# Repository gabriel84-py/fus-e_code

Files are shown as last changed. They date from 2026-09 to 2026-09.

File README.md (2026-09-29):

# LUNATIK

A flight computer we designed, built and flew in a our model rocket, to find out which way of detecting apogee really fires first: the barometer, the accelerometer, or both fused with a Kalman filter.

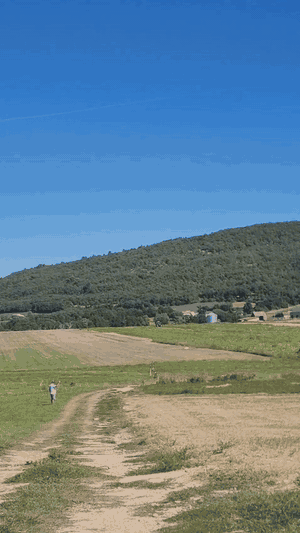
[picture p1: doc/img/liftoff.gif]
LUNATIK lifting off


**[Watch the full flight](video-first-flight-LUNATIK.mp4)** | **[Schematic (PDF)](Schematic_LUNATIK-v1.pdf)** | **[Try the ground station without a rocket](#try-it-without-a-rocket)**

Raspberry Pi Pico 2 (RP2350), CircuitPython, LoRa telemetry, SD logging. Made by Sidonie and me (Gabriel), two high school students from Villeneuve-lès-Avignon, France, for the French Physics Olympiad (Olympiades de Physique France).

## Why we built it

Most hobby flight computers detect apogee the same way: wait until the altitude drops a few samples in a row, then fire the parachute. I wanted to know if that actually works, and how late it is.

The whole project ended up fitting in one sentence: **the accelerometer is a good clock but a bad ruler, and the barometer is a good ruler but a bad clock.**

- Integrate an accelerometer twice and any tiny bias `b` becomes an altitude error of `1/2 b t^2`. Great for the first second, useless after ten.
- A barometer knows where you are, but to be sure you've passed the top you have to wait until you're `dh` below it. That costs `sqrt(2 dh / g)` seconds, however good the sensor is.

So LUNATIK fuses both with a 3-state Kalman filter (altitude, vertical velocity, accelerometer bias), and we measured whether that is actually better instead of assuming it.

## It flew

LUNATIK flew in September 2026. The GIF at the top is the liftoff, and the full clip is in the repo: [`video-first-flight-LUNATIK.mp4`](video-first-flight-LUNATIK.mp4).

## What's on the board

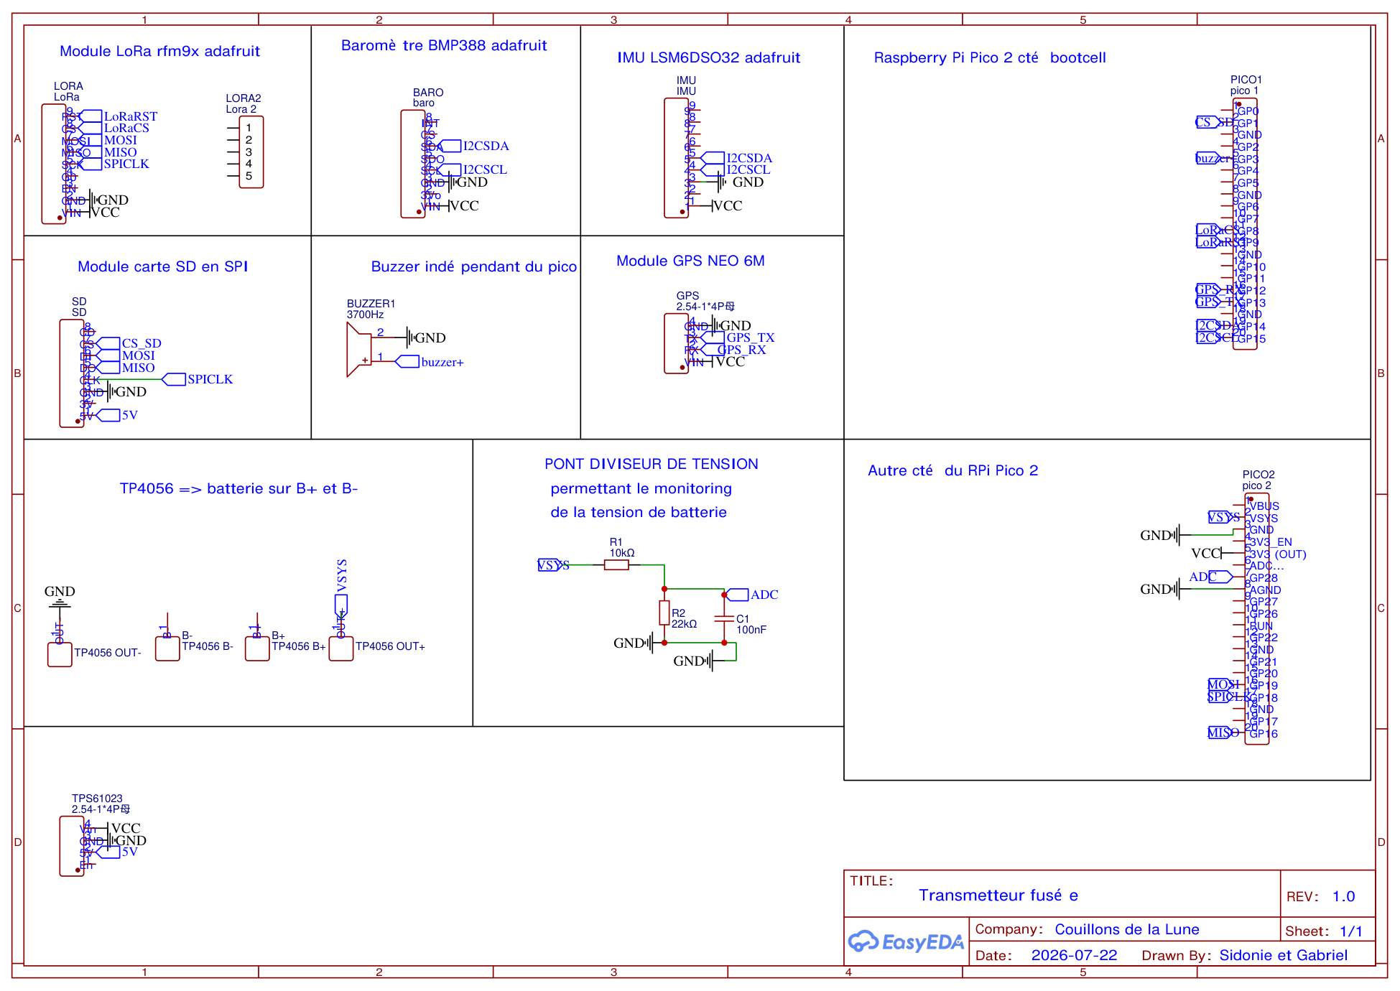
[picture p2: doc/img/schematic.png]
LUNATIK schematic


| Part | Job |
|---|---|
| Raspberry Pi Pico 2 (RP2350) | runs everything, in CircuitPython |
| BMP388 (I2C) | pressure, so altitude |
| LSM6DSO32 (I2C) | accelerometer +/-16 g and gyro, 208 Hz |
| RFM9x LoRa 868 MHz (SPI) | telemetry to the ground |
| SD card module (SPI) | full flight log in CSV |
| NEO-6M GPS (UART) | position, to find the rocket afterwards |
| TP4056 + LiPo | charging and power |
| TPS61023 boost | 5 V for the SD card |
| 3700 Hz buzzer | so you can hear what state it's in |
| 10k/22k divider + 100 nF | battery voltage on the ADC |

Schematic done in EasyEDA by both of us.

## How it works

**State machine.** `PRE_LAUNCH -> BOOST -> COAST -> APOGEE -> DESCENT -> LANDED`. Every transition needs several confirming samples and has a backup timer, because we only had one motor and the firmware had to work the first time.

**Kalman filter.** The 3x3 covariance is stored as 6 plain floats instead of a matrix, so no numpy and no allocation on the Pico. The full update costs 0.51 ms. The process noise isn't the datasheet value: it has to cover gravity leaking into the axis when the rocket tilts, which the model doesn't know about.

**Apogee.** We first tried "N decreases in a row" and threw it out after measuring it. Near apogee the rocket drops about 4 cm between two samples, while the noise on that difference is about 24 cm. The signal-to-noise ratio is 0.18, so the criterion is basically flipping a coin. LUNATIK instead fires when the *fused* altitude is 0.51 m (3 sigma of the baro noise) below the highest point seen, confirmed twice.

**Radio off during the climb.** One LoRa packet blocks the loop for about 200 ms. In simulation, leaving it on during the climb made the altitude error go from 0.21 to 0.54 m, so the radio stays quiet from liftoff to apogee.

## Numbers

Measured on the real board, except the two lines marked "sim" (OpenRocket trajectory with realistic noise added).

| | |
|---|---|
| Loop rate during the climb | 32.3 Hz |
| Barometer read (OSx8) | 21.4 ms, 69 % of the loop |
| Full Kalman update | 0.51 ms, 1.6 % of the loop |
| Baro noise, measured | 15.7 cm |
| Kalman altitude uncertainty | 8.7 cm (1.8x better than the raw baro) |
| Apogee detection delay (sim) | 0.37 +/- 0.02 s |
| Lead over the motor's ejection charge (sim) | 0.188 s |

The one that surprised me: the maths costs almost nothing. The barometer eats most of the loop, so optimising the filter would have been pointless. Reading pressure and temperature in one call instead of two took the loop from 19 Hz to 32 Hz.

## Things that went wrong

- **The SD card was wired to VBUS on the V3 board.** It worked perfectly on the bench, because the bench was on USB. On battery, in flight, it would have been dead. We only caught it by writing a script to check the Gerbers before ordering. The new board powers it through the TPS61023 boost.
- **The burnout threshold was never crossed.** We took it from OpenRocket's "vertical acceleration" column, but that column doesn't include gravity, and an accelerometer measures gravity plus acceleration. The rocket always switched to COAST on the 5 s backup timer, 2.3 s late. Now the threshold is compared to the real sensor value (column + 9.81).
- **Apogee fired on the launch pad.** Feeding the detector raw baro altitude, noise alone crossed the threshold before liftoff in 2 runs out of 5. Feeding it the Kalman altitude fixed it.
- **Still open:** under the parachute the rocket swings, gravity leaks into the accelerometer axis, and the filter becomes overconfident (1.5 m of real error for 8.5 cm announced). Fixing that means adding attitude from the gyro, so going from 3 states to at least 6.

## The flight
 
LUNATIK flew in September 2026 and logged the whole thing to SD at about 30 Hz. This is the raw log, straight from the card:
 
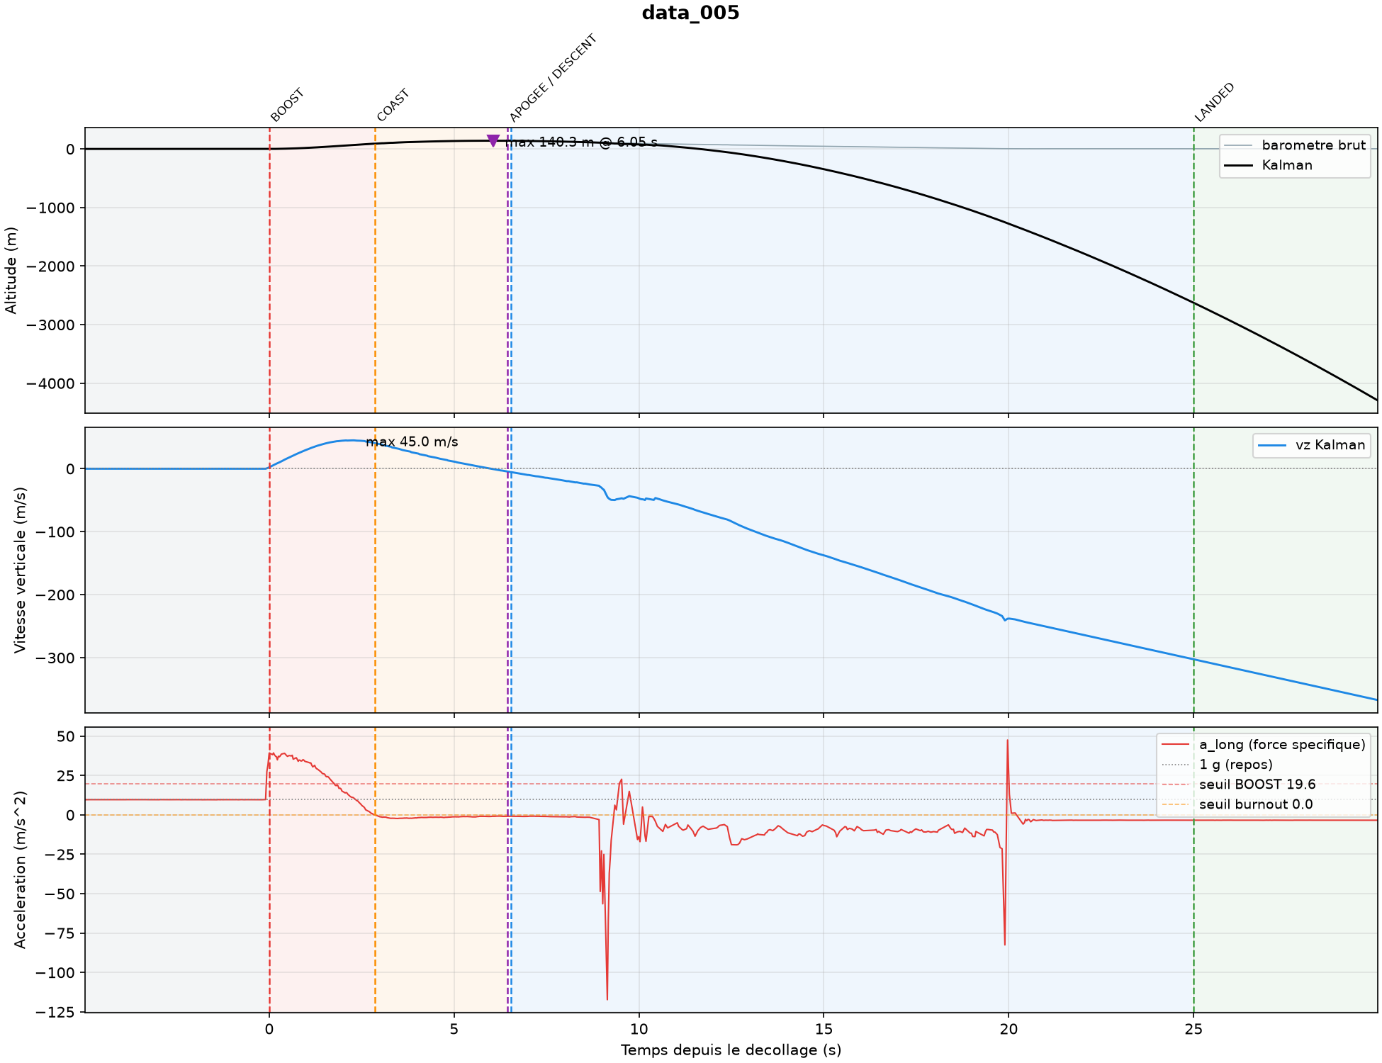
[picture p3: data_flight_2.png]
Flight data

 
| | |
|---|---|
| Apogee | 140 m, 6.1 s after liftoff |
| Peak acceleration | 4.0 g, top speed 45 m/s |
| Liftoff detected | 63 ms after the first sample above 2 g (needs 3 in a row) |
| Burnout detected | 2.9 s after liftoff, on the sensor threshold, not the backup timer |
| Apogee called by LUNATIK | **0.45 s after the top** (simulation said 0.37 s) |
| Motor ejection charge | 2.5 s after LUNATIK called apogee, 24 m lower |
| Descent under parachute | 9.3 m/s |
| Landing detected | 5 s after touchdown, as designed |
 
The result I care most about: the motor's delay charge opened the parachute 2.5 s after the top, with the rocket already 24 m down. LUNATIK knew it was at apogee half a second after the top. On this flight, electronic deployment would have opened the chute a lot earlier and higher.
 
**What went wrong in the air.** Look at the blue curve after the parachute opens. Under the chute the rocket hangs upside down, so the accelerometer reads about -10 m/s^2 instead of +10. The filter still subtracts its +9.81 bias, sees 20 m/s^2 of acceleration that doesn't exist, and drifts. Once it was more than 30 m off, the innovation gate (there to protect the filter from one bad baro reading) started rejecting *every* baro reading, so it never came back. It ended the flight thousands of meters underground.
 
Two lessons: a gate needs a way back (reset on the barometer after too many rejections), and the model needs attitude, or at least needs to stop trusting the accelerometer under the chute. The good news is that landing detection runs on the raw barometer, not on the filter, so the state machine still called LANDED correctly.
 
<p align="center">
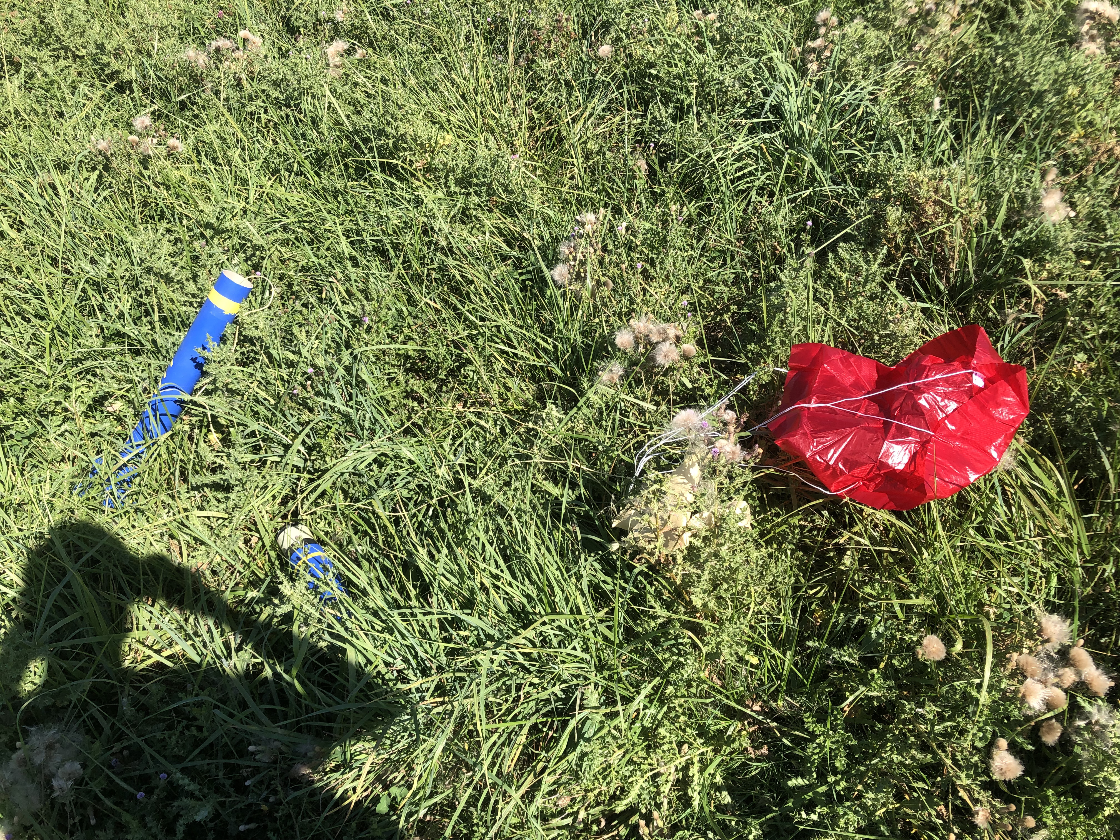
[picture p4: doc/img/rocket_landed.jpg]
The rocket after landing
  
</p>

## Try it without a rocket

The ground station has a simulation mode that generates fake telemetry, so you can see it running with no hardware:

```bash
git clone https://github.com/gabriel84-py/fus-e_code.git
cd fus-e_code/scripts
pip install pyserial matplotlib
python dashboard.py --simulate
```

Needs Python 3 with Tkinter (included with the python.org installer on Windows and macOS; `sudo apt install python3-tk` on Debian/Ubuntu).

To run the real thing: flash CircuitPython on a Pico 2, copy everything in `src/` to the `CIRCUITPY` drive, and format the SD card as FAT32 (full format, not quick). On the pad, the accelerometer bias shown on the debug line has to settle near **+9.81**. If it goes to -9.81 the axis is upside down and the rocket will never detect liftoff.

## About the logged hours

Hackatime only tracked the code. Everything on the hardware side (soldering, wiring, building and integrating the rocket, launch day) wasn't recorded, because I didn't know there was a tool to record build sessions until the rocket had already flown. So the hours on this project are lower than the time I actually spent on it.

## Credits

- Adafruit for the CircuitPython drivers, OpenRocket for the trajectory simulations.
- Olympiades de Physique France, and Hack Club for Stardance.

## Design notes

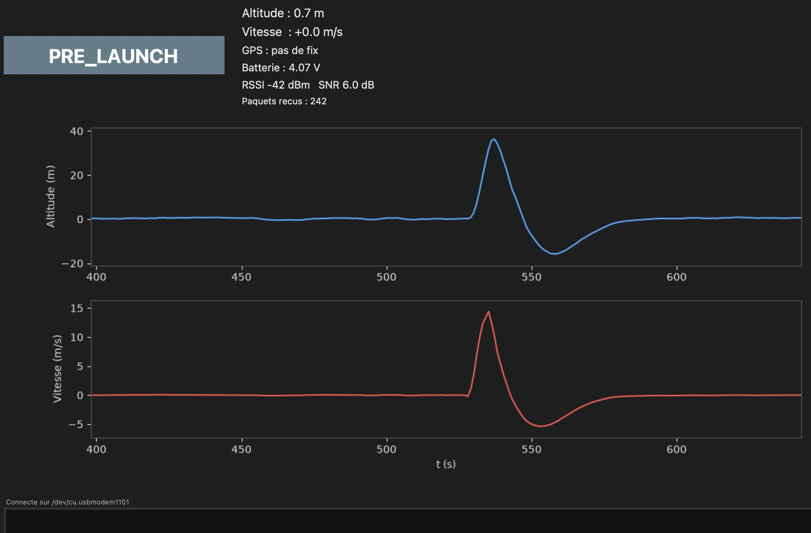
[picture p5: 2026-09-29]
doc/img/dashboard.png

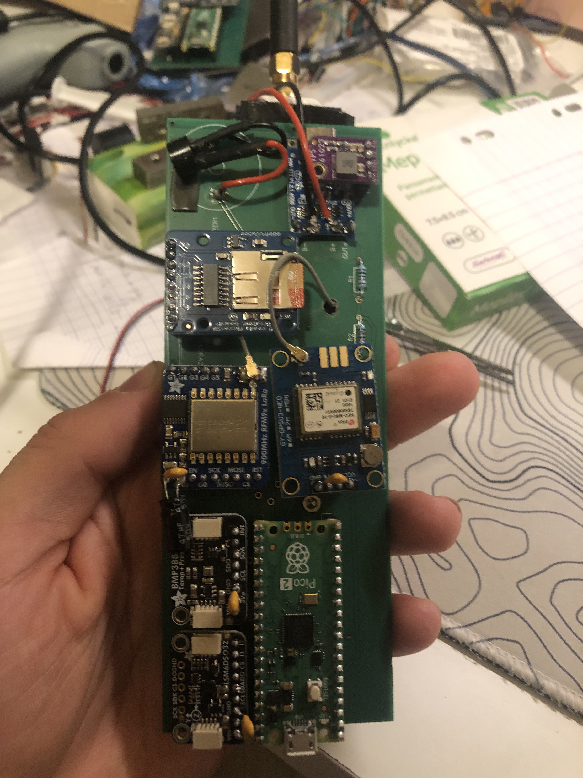
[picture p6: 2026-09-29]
doc/img/hero.jpg

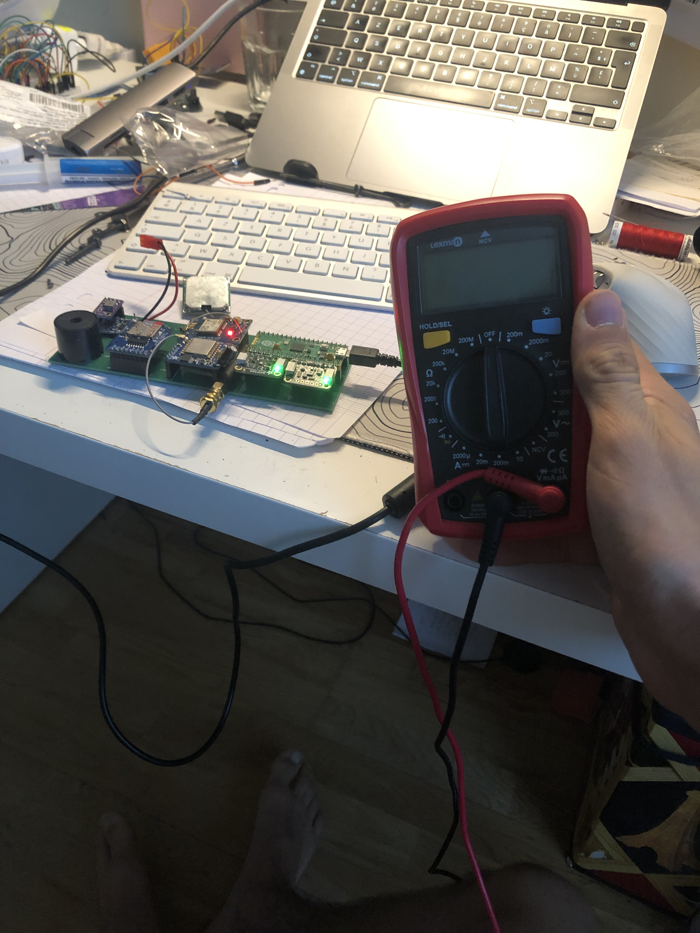
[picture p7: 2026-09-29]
doc/img/multimeter_pcb.jpg

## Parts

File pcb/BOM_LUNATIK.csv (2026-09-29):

ID | Name | Designator | Footprint | Quantity | Manufacturer Part | Manufacturer | Supplier | Supplier Part | Price
1 | 2.54-1*4P母 | TPS61023,GPS | HDR-TH_4P-P2.54-V-F | 2 | 2.54-1*4P母 | BOOMELE(博穆精密) | LCSC | C2718488 | 0.079
2 | TP4056 B+ | B+ | HDR-TH_1P-P2.54-V-M | 1 | PZ254V-11-01P | XFCN(兴飞) | LCSC | C492400 | 0.018
3 | TP4056 B- | B- | HDR-TH_1P-P2.54-V-M | 1 | PZ254V-11-01P | XFCN(兴飞) | LCSC | C492400 | 0.018
4 | TP4056 OUT+ | OUT+ | HDR-TH_1P-P2.54-V-M | 1 | PZ254V-11-01P | XFCN(兴飞) | LCSC | C492400 | 0.018
5 | TP4056 OUT- | OUT- | HDR-TH_1P-P2.54-V-M | 1 | PZ254V-11-01P | XFCN(兴飞) | LCSC | C492400 | 0.018
6 | baro | BARO | HDR-TH_8P-P2.54-V-F | 1 | ZX-PM2.54-1-8PY | Megastar(兆星) | LCSC | C7499328 | 0.147
7 | SD | SD | HDR-TH_8P-P2.54-V-F | 1 | ZX-PM2.54-1-8PY | Megastar(兆星) | LCSC | C7499328 | 0.147
8 | 100nF | C1 | C0402 | 1 | CC0402KRX7R7BB104 | YAGEO(国巨) | LCSC | C60474 | 0.005
9 | IMU | IMU | HDR-TH_9P-P2.54-V-F-1 | 1 | PM2.54-1*9 | ZHOURI(洲日) | LCSC | C5224028 | 0.124
10 | LoRa | LORA | HDR-TH_9P-P2.54-V-F-1 | 1 | PM2.54-1*9 | ZHOURI(洲日) | LCSC | C5224028 | 0.124
11 | Lora 2 | LORA2 | HDR-TH_5P-P2.54-V-F | 1 | 2.54-1*5P母 | BOOMELE(博穆精密) | LCSC | C50950 | 0.084
12 | pico 1 | PICO1 | HDR-TH_20P-P2.54-V-F | 1 | ZX-PM2.54-1-20PY | Megastar(兆星) | LCSC | C7499336 | 0.262
13 | pico 2 | PICO2 | HDR-TH_20P-P2.54-V-F | 1 | ZX-PM2.54-1-20PY | Megastar(兆星) | LCSC | C7499336 | 0.262
14 | 10kΩ | R1 | RES-TH_BD2.5-L6.5-P10.50-D0.6 | 1 | MFR0W4F1002A50 | UNI-ROYAL(厚声) | LCSC | C57436 | 0.014
15 | 22kΩ | R2 | RES-TH_BD2.3-L6.5-P10.50-D0.5 | 1 | MF1/4W-22KΩ±1% T | CCO(千志电子) | LCSC | C119354 | 0.011
16 | 3700Hz | BUZZER1 | BUZ-TH_BD23.0-P15.00-D0.8-FD | 1 | YX-YD2319 | YUEXIN(悦馨) | LCSC | C781874 | 0.561

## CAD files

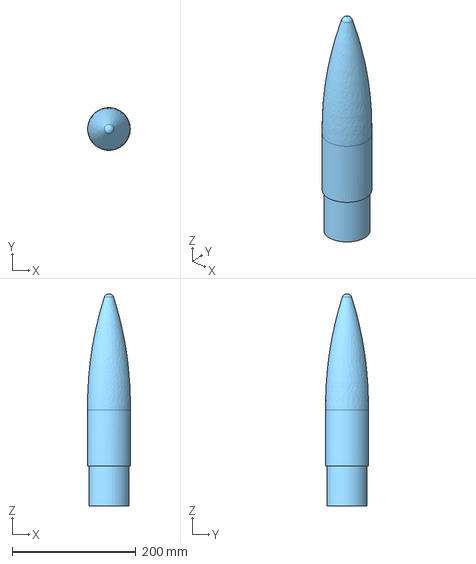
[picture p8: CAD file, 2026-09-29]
cad/nose-cone_LUNATIK.stp
69.1 x 69.2 x 343.0 mm

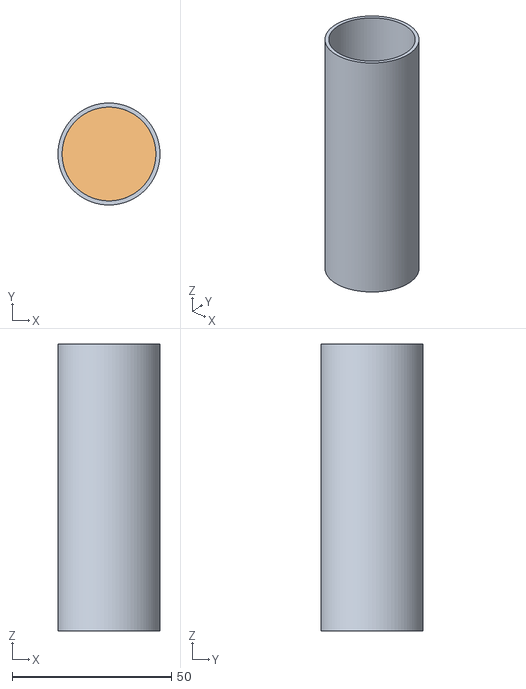
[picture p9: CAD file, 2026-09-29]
cad/LUNATIK.obj
32.0 x 32.0 x 90.0
1_Tube interne
2_Rétension moteur

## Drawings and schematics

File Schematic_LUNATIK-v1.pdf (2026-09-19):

## Raspberry Pi Pico 2 c t bootcell

## Barom tre BMP388 adafruit

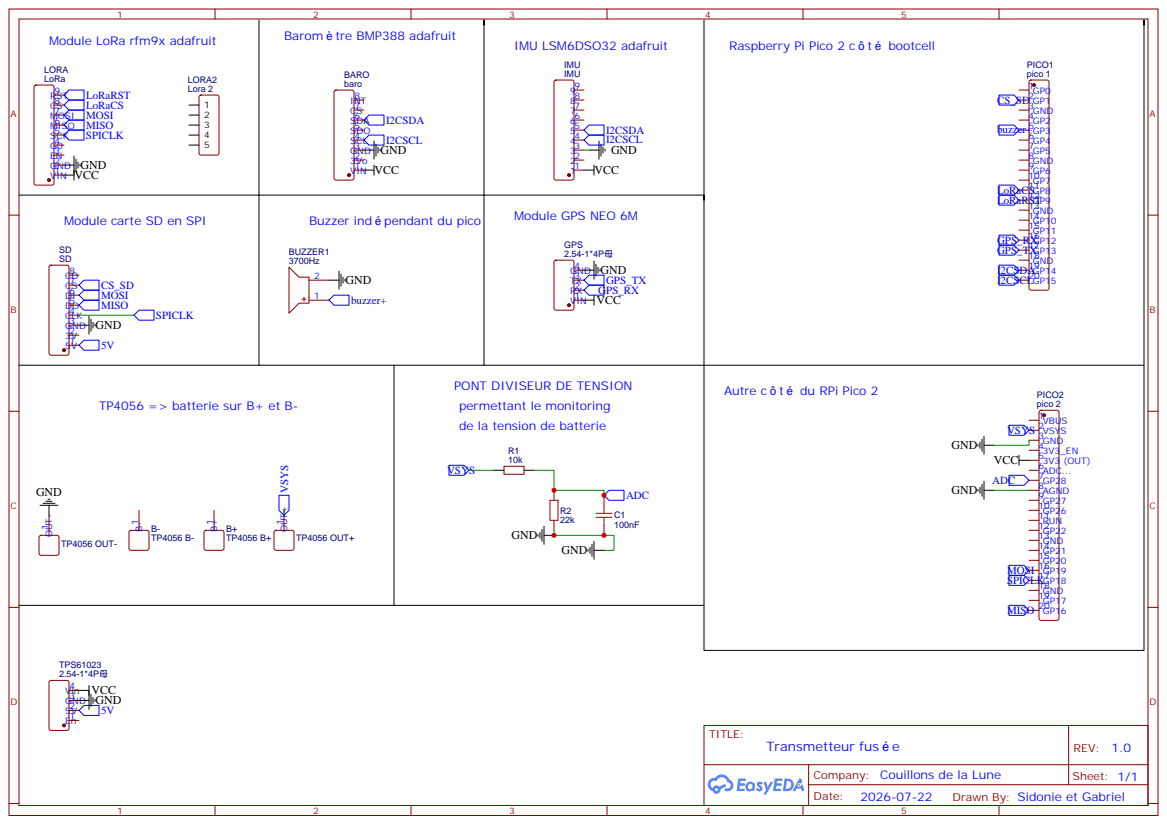
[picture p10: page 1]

PONT DIVISEUR DE TENSION
permettant le monitoring
de la tension de batterie

Autre c t du RPi Pico 2

Company: Couillons de la Lune

Drawn By: Sidonie et Gabriel

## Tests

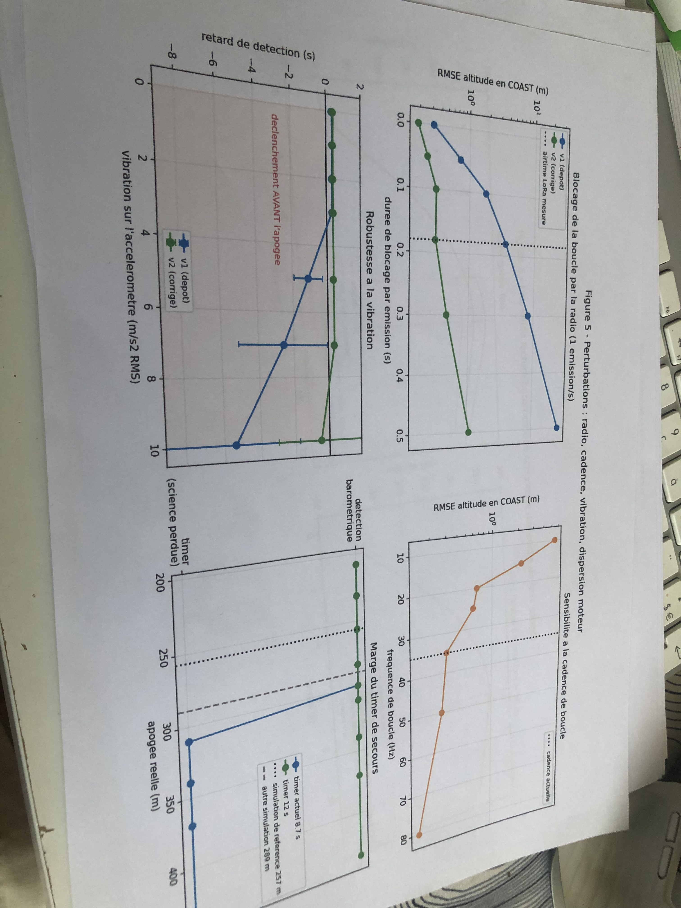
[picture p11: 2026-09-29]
doc/img/benchmark_2.jpg

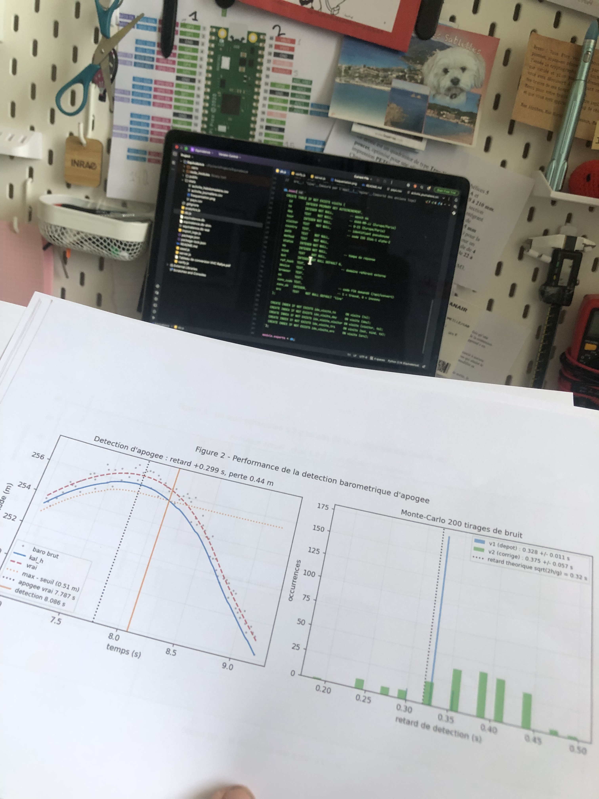
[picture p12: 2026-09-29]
doc/img/kalman_apogee_detection_benchmark.jpg

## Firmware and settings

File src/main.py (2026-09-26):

# buzzer sur GP3 : allume en continu de PRE_LAUNCH a LANDED
import battery as battery, datalog as datalog, kalman as kalman, sensors as sensors, state_machine as state_machine, telemetry as telemetry
import board
import busio
import digitalio
import time

DT = 0.01
TELEMETRY_PERIOD = 1.0
GROUND_PRESSURE_SAMPLES = 50   # mesures moyennees pour la ref baro sol
KALMAN_UPDATE_PERIOD = 0.22    # periode de correction barometrique

# recalage continu du biais accelerometrique pendant PRE_LAUNCH. Au repos, la
# force specifique lue sur l'axe longitudinal EST le biais, quelle que soit
# l'orientation. Ce recalage rend le vol insensible a l'assiette de la fusee
# au moment de la calibration initiale : teste calibre a 90 degres (fusee
# couchee), b converge quand meme a 9.807 en 20 s d'attente. Il est gele des
# qu'un echantillon depasse le seuil de decollage, pour qu'un choc ou le
# debut de la poussee ne vienne jamais polluer b.
ALPHA_BIAIS = 0.02             # tau = 1.4 s a 35 Hz

DEBUG_FREQ = True     # etat de vol sur le REPL, 1x/s ; False au jour J
BUZZER_ENABLED = False  # False au banc pour couper le son sans changer la logique

buzzer = digitalio.DigitalInOut(board.GP3)
buzzer.direction = digitalio.Direction.OUTPUT

time.sleep(20)

buzzer.value = True
time.sleep(1)
buzzer.value = False



def compute_altitude(pressure_hpa, sea_level_hpa):
    # formule de adafruit_bmp3xx.altitude, appliquee a une pression deja lue
    # pour eviter une 2e conversion du BMP rien que pour l'altitude
    return 44330.0 * (1.0 - (pressure_hpa / sea_level_hpa) ** 0.1903)


sta = state_machine.StateMachine()
sta.state = "SETUP"


def set_buzzer(state):
    # seul point d'ecriture sur GP3 : BUZZER_ENABLED coupe le son partout
    buzzer.value = state and BUZZER_ENABLED


SPI = busio.SPI(board.GP18, MOSI=board.GP19, MISO=board.GP16)
radio_cs_pin, radio_reset_pin = board.GP8, board.GP9

# init complete + calage baro, protegee : une panne ici bloque au sol avec
# une alarme sonore plutot que de decoller avec une chaine de mesure
# incomplete
try:
    sen = sensors.Sensors()
    bat = battery.Battery()
    dat = datalog.Datalog(SPI)
    tel = telemetry.Telemetry(SPI, radio_cs_pin, radio_reset_pin)

    kal = kalman.Kalman(DT, sen)
    kal_cal = kal.calibrate(300)

    # pression sol = reference 0 m, fusee posee au sol, avant le sleep(5)
    ground_pressure_samples = []
    for _ in range(GROUND_PRESSURE_SAMPLES):
        ground_pressure_samples.append(sen.baro_pt[0])
        time.sleep(0.05)
    sen.bmp.sea_level_pressure = (sum(ground_pressure_samples) / GROUND_PRESSURE_SAMPLES)

except Exception as exc:
    # bips rapides en boucle : motif distinct de tout etat de vol normal
    print("ECHEC INIT:", exc)
    beep_state = False
    while True:
        beep_state = not beep_state
        set_buzzer(beep_state)
        time.sleep(0.1)

time.sleep(5)
sta.state = "PRE_LAUNCH"

# bip continu de PRE_LAUNCH a LANDED, un seul passage a True suffit
set_buzzer(True)

t_prev_pred = time.monotonic()
t_prev_upd = time.monotonic()
t_prev_tel = time.monotonic()
t_prev_debug = time.monotonic()

# valeurs de repli : si la toute premiere lecture d'un capteur echoue, la
# boucle doit quand meme pouvoir tourner
baro_hpa, baro_temp = sen.bmp.sea_level_pressure, 15.0
baro_alt = 0.0
imu_accel = (0.0, 0.0, 9.81)
gyro = (0.0, 0.0, 0.0)
batv = 0.0
# derniere position GPS connue ; ne retombe pas a 0.0/0 si le fix est perdu
lat, lon, alt, sat = 0.0, 0.0, 0.0, 0

n_err_baro = 0
n_err_imu = 0
n_err_log = 0

while True:
    # Chaque sous-systeme est protege SEPAREMENT, et l'estimation comme la
    # machine d'etat ne sont JAMAIS sautees. Avec un try/except unique autour
    # de toute la boucle, un bus I2C bloque (esclave qui tient SDA bas sous
    # vibration) figeait definitivement la machine d'etat : plus de
    # transition, plus de detection d'apogee, plus de log.
    sec = time.monotonic()

    baro_ok = True
    try:
        baro_hpa, baro_temp = sen.baro_pt
        baro_alt = compute_altitude(baro_hpa, sen.bmp.sea_level_pressure)
    except Exception:
        baro_ok = False
        n_err_baro += 1

    try:
        imu_accel = sen.imu_accel
        gyro = sen.imu_gyro
    except Exception:
        n_err_imu += 1   # on conserve la derniere mesure valide

    if sta.state == "DESCENT" or sta.state == "LANDED" or sta.state == "PRE_LAUNCH":
        try:
            gps = sen.gps_data
            if gps is not None:
                lat, lon, alt, sat = gps
        except Exception:
            pass

    try:
        batv = bat.tension
    except Exception:
        pass

    # ---- estimation : jamais sautee -------------------------------------
    dt_pred = sec - t_prev_pred
    t_prev_pred = sec
    kal_h, kal_v, kal_b = kal.prediction(dt_pred, imu_accel[2])

    if baro_ok and sec - t_prev_upd >= KALMAN_UPDATE_PERIOD:
        kal_h, kal_v, kal_b = kal.update(baro_alt)
        t_prev_upd = sec

    # au sol et sous le seuil de decollage : h et v sont connus exactement,
    # on les force plutot que de laisser la moindre derive s'accumuler
    # pendant l'attente au pas de tir. Des le premier echantillon au-dessus
    # du seuil on relache, pour ne pas perdre les 86 ms d'integration que
    # dure la confirmation du decollage.
    if sta.state == "PRE_LAUNCH" and imu_accel[2] < sta.accelLimitForBoost:
        kal.b += ALPHA_BIAIS * (imu_accel[2] - kal.b)
        kal.h = 0.0
        kal.v = 0.0
        kal_h, kal_v, kal_b = 0.0, 0.0, kal.b

    # ---- machine d'etat : jamais sautee ---------------------------------
    sta.update(sec, imu_accel[2], kal_v, kal_h, baro_alt if baro_ok else None)

    # ---- journalisation --------------------------------------------------
    try:
        dat.log(
            sec, sta.state, imu_accel, gyro,
            baro_hpa, baro_temp, baro_alt,
            lat, lon, alt,
            kal_h, kal_v, batv
        )
    except Exception:
        n_err_log += 1

    # ---- radio : coupee entre le decollage et l'apogee --------------------
    # chaque emission bloque la boucle ~180 ms. En laissant la radio active
    # pendant la montee, la RMSE d'altitude en COAST passait de 0.31 m a
    # 3.55 m : prediction() se retrouve a integrer 0.5*a*dt^2 sur un pas de
    # 0.21 s en pleine phase de jerk eleve. Accessoirement, 175 ms par
    # seconde font 17.5 % de cycle de service sur une bande 868.0 MHz
    # limitee a 1 %.
    if (sta.state in ("PRE_LAUNCH", "DESCENT", "LANDED")
            and sec - t_prev_tel >= TELEMETRY_PERIOD):
        try:
            to_send = dat._formatter_compact(
                sec, sta.state, imu_accel, gyro,
                baro_hpa, baro_temp, baro_alt,
                lat, lon, alt,
                kal_h, kal_v, batv
            )
            tel.send(to_send)
        except Exception:
            pass
        t_prev_tel = sec

    if DEBUG_FREQ and sec - t_prev_debug >= 1.0:
        # go/no-go avant allumage : en PRE_LAUNCH, h_kalman doit rester a
        # +/- 1 m de 0 et v a +/- 0.2 m/s, et biais doit etre proche de 9.81
        print(
            "etat=", sta.state,
            " h_kal=", round(kal_h, 2), "m",
            " h_baro=", round(baro_alt, 2), "m",
            " v=", round(kal_v, 2), "m/s",
            " biais=", round(kal.b, 3),
            " p_hh=", round(kal.p_hh, 4),
            " rejets=", kal.n_rejets,
            " err(baro/imu/log)=", n_err_baro, n_err_imu, n_err_log,
            " batt=", batv, "V",
        )
        t_prev_debug = sec

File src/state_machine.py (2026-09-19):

import time
import apogee as apogee


class StateMachine:
    """
    PRE_LAUNCH -> BOOST -> COAST -> APOGEE -> DESCENT -> LANDED

    Toutes les constantes de temps sont comptees depuis t_decollage.
    Convention capteur : accel est la FORCE SPECIFIQUE lue sur l'axe
    longitudinal (+9.81 au repos, 0 en chute libre), pas l'acceleration
    cinematique. Tout seuil issu d'une simulation OpenRocket doit donc etre
    derive de la colonne "Acceleration verticale" + 9.81.
    """

    # decollage : N echantillons consecutifs au-dessus du seuil.
    # Avec un seul echantillon, un choc de 2 g au pas de tir (pose sur le
    # rail, insertion de l'inflammateur, rafale) faisait derouler toute la
    # machine d'etat en 13 s et la laissait en LANDED avant le vrai
    # decollage : vol entier perdu. Le vrai decollage fournit 77 echantillons
    # consecutifs au-dessus du seuil, la marge est enorme.
    N_BOOST_CONFIRM = 3

    # garde-fou supplementaire : si l'altitude n'a pas grimpe apres
    # T_CONFIRM_S, c'etait un faux depart, on rearme.
    ALT_CONFIRM_M = 15.0
    T_CONFIRM_S = 1.5

    T_BOOST_MAX = 5.0

    # timer de secours d'apogee. A 8.7 s il gagnait sur la detection
    # barometrique des que l'apogee reelle depassait ~300 m, soit 0.2 s de
    # marge sur la simulation a 289 m : la mesure barometrique, qui est tout
    # l'objet du projet, n'aurait jamais eu lieu. Aucune charge pyro n'etant
    # commandee par la carte, ce timer ne sert qu'a etiqueter l'etat : il doit
    # etre le plus tardif possible. Valide jusqu'a 434 m d'apogee.
    T_APOGEE_BACKUP = 12.0

    # atterrissage. Le critere |v| < 0.5 m/s ne peut pas se declencher : une
    # fois la fusee couchee, l'axe longitudinal lit ~0 au lieu de +9.81 et le
    # filtre croit etre en chute libre (vitesse mesuree a -21 m/s en moyenne,
    # 0 % des echantillons sous 0.5 m/s). On utilise la stabilite de
    # l'altitude BAROMETRIQUE BRUTE, qui elle est juste.
    T_LANDED_MAX = 90.0     # 50 s etait plus court que la descente sous un
                            # parachute a 5 m/s depuis 257 m (51 s)
    LANDED_BAND_M = 2.5
    LANDED_HOLD_S = 5.0

    def __init__(self):
        self.apogeedetec = apogee.ApogeeDetection()
        self.state_list = ["PRE_LAUNCH", "BOOST", "COAST", "APOGEE",
                           "DESCENT", "LANDED"]
        self.state = self.state_list[0]

        self.accelLimitForBoost = 19.6    # m/s2 lus, soit 2 g
        # la force specifique ne descend jamais sous -3.4 m/s2 entre le
        # decollage et l'apogee (trainee seule) : l'ancien seuil de -12 n'etait
        # jamais franchi et BOOST->COAST se faisait toujours par le timer 5 s,
        # soit 2.3 s apres le vrai burnout. 0.0 est franchi des la fin de
        # poussee et reste loin des +19.6 de la phase propulsee.
        self.accelLimitForBurnOut = 0.0

        self.t_decollage = 0.0  # !!!! en SECONDES !!!!
        self.h_decollage = 0.0
        self.n_boost = 0        # lu par main.py pour geler le recalage du biais
        self.h_ref_landed = None
        self.t_landed_start = 0.0

    def update(self, t, accel, kalman_speed, kh_m, baro_alt=None):
        # baro_alt : altitude barometrique BRUTE, utilisee seulement pour la
        # detection d'atterrissage. Optionnel pour rester compatible avec les
        # anciens appels a 4 arguments.
        h_land = kh_m if baro_alt is None else baro_alt
        s = self.state

        if s == "PRE_LAUNCH":
            if accel >= self.accelLimitForBoost:
                self.n_boost += 1
            else:
                self.n_boost = 0
            if self.n_boost >= self.N_BOOST_CONFIRM:
                self.state = "BOOST"
                self.t_decollage = t
                self.h_decollage = kh_m

        elif s == "BOOST":
            dt = t - self.t_decollage
            if dt > self.T_CONFIRM_S and (kh_m - self.h_decollage) < self.ALT_CONFIRM_M:
                # faux depart : on rearme completement
                self.state = "PRE_LAUNCH"
                self.n_boost = 0
                self.apogeedetec.reset()
            elif accel <= self.accelLimitForBurnOut or dt >= self.T_BOOST_MAX:
                self.state = "COAST"

        elif s == "COAST":
            if self.apogeedetec.detection(kh_m):
                self.state = "APOGEE"
            elif (t - self.t_decollage) >= self.T_APOGEE_BACKUP:
                self.state = "APOGEEtimer"

        elif s == "APOGEE" or s == "APOGEEtimer":
            self.state = "DESCENT"
            self.h_ref_landed = None

        elif s == "DESCENT":
            if (t - self.t_decollage) >= self.T_LANDED_MAX:
                self.state = "LANDED"
            elif (self.h_ref_landed is None
                  or abs(h_land - self.h_ref_landed) > self.LANDED_BAND_M):
                # l'altitude bouge encore : on redemarre la fenetre
                self.h_ref_landed = h_land
                self.t_landed_start = t
            elif (t - self.t_landed_start) >= self.LANDED_HOLD_S:
                self.state = "LANDED"

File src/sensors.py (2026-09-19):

import board
import busio
import digitalio
import adafruit_bmp3xx
import time
import adafruit_gps
from adafruit_lsm6ds import AccelRange, Rate
from adafruit_lsm6ds.lsm6dso32 import LSM6DSO32


class Sensors:
    def __init__(self):
        # I2C Fast Mode (400 kHz) : BMP388 et LSM6DSO32 le supportent tous
        # les deux, et chaque property fait sa propre transaction I2C
        self.i2c = busio.I2C(board.GP15, board.GP14, frequency=400000)
        self.baro_setup()
        self.imu_setup()
        self.gps_setup()

    def baro_setup(self):
        self.bmp = adafruit_bmp3xx.BMP3XX_I2C(self.i2c)
        # BMP3XX.__init__ appelle self.reset(), qui remet TOUS les registres
        # par defaut : OSR x1 en pression et en temperature. Sans les trois
        # lignes ci-dessous le capteur vole a OSx1 (sigma ~ 0.40 m) alors que
        # kalman.r = 0.17^2 est calibre pour OSx8 -> r sous-estime d'un
        # facteur 5.5 et toute la caracterisation de bruit du memoire decrit
        # une configuration dans laquelle la fusee ne vole pas.
        self.bmp.pressure_oversampling = 8
        self.bmp.temperature_oversampling = 1
        # IIR laisse a 0 : le filtre du capteur ajouterait son propre retard
        # et invaliderait le sigma mesure au banc. C'est le Kalman qui filtre.
        self.bmp.filter_coefficient = 0
        return self.bmp

    def imu_setup(self):
        self.imu = LSM6DSO32(self.i2c)
        # le driver force RANGE_8G a l'init, soit 78.5 m/s2, pour un pic de
        # force specifique simule a 71.6 m/s2 (7.30 g) : 10 % de marge, que
        # les transitoires d'allumage et la vibration structurelle mangent.
        self.imu.accelerometer_range = AccelRange.RANGE_16G
        # ODR 208 Hz pour un echantillonnage a 35 Hz : reduit le repliement
        # de la vibration dans la bande utile
        self.imu.accelerometer_data_rate = Rate.RATE_208_HZ
        self.imu.gyro_data_rate = Rate.RATE_208_HZ
        return self.imu

    def gps_setup(self):
        RX = board.GP13
        TX = board.GP12
        # 0.2 s : assez pour terminer une trame deja commencee (83 ms a 9600
        # bauds) sans jamais figer la boucle une seconde entiere. Plus court
        # tronquerait les trames et casserait le parsing.
        uart = busio.UART(TX, RX, baudrate=9600, timeout=0.2,
                          receiver_buffer_size=256)
        self.gps = adafruit_gps.GPS(uart, debug=False)
        self.gps.send_command(b'PMTK314,0,1,0,1,0,0,0,0,0,0,0,0,0,0,0,0,0,0,0')
        self.gps.send_command(b'PMTK220,1000')
        self.last_print = time.monotonic()
        return self.gps, self.last_print

    @property
    def baro_pt(self):
        """Pression (hPa) ET temperature (degC) en UNE seule conversion.

        adafruit_bmp3xx declenche une conversion forcee complete a chaque
        appel de _read(), et les properties .pressure et .temperature
        l'appellent chacune separement : lire les deux coutait deux
        conversions par tour de boucle, soit ~38 ms a OSx8.
        """
        p, t = self.bmp._read()
        return p / 100.0, t

    @property
    def baro_pa(self):
        return self.bmp.pressure

    @property
    def baro_alt(self):
        # redeclenche sa propre lecture I2C de la pression en interne ; si
        # baro_pt a deja ete lu ce tour-ci, preferer recalculer l'altitude
        # a partir de cette valeur (cf compute_altitude() dans main.py)
        return self.bmp.altitude

    @property
    def baro_temp(self):
        return self.bmp.temperature

    @property
    def imu_accel(self):
        # le capteur est oriente de telle maniere que l'axe z de la fusee est
        # aligne en sens et direction avec l'axe x de l'IMU. L'indice [2] du
        # tuple retourne est donc l'axe LONGITUDINAL de la fusee.
        self.accel_x, self.accel_y, self.accel_z = self.imu.acceleration
        return self.accel_z, self.accel_y, self.accel_x

    @property
    def imu_gyro(self):
        self.gyro_x, self.gyro_y, self.gyro_z = self.imu.gyro
        return self.gyro_x, self.gyro_y, self.gyro_z

    @property
    def gps_data(self):
        self.gps.update()
        if not self.gps.has_fix:
            return None
        lat = self.gps.latitude
        lon = self.gps.longitude
        if lat is None or lon is None:
            return None
        alt = self.gps.altitude_m if self.gps.altitude_m is not None else 0.0
        sat = self.gps.satellites if self.gps.satellites is not None else 0
        return lat, lon, alt, sat

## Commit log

2026-07-27 sats nb and good lib for IMU
2026-08-27 datalog & battery
2026-08-28 erros for sido & telem corrigé
    [datalog.py, kalman.py, sensors.py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]
2026-08-28 intervertion x et z imu
2026-08-30 sans init de sensors dans datalog
2026-09-06 corrections sensors & battery
    [sensors.py]
2026-09-15 main : gerer les exeptions git add .
2026-09-15 main : pr pas me peter les oreilles...
2026-09-15 modifs freq 33-35Hz
2026-09-19 fw v3
    [plancher_bruit.csv]
